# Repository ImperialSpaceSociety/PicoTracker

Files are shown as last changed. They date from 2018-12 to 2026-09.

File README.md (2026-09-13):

# PicoTracker







PicoTracker is a lightweight, low-cost high-altitude balloon tracking platform built around an STM8 microcontroller, HC-12 radio hardware, u-blox GPS, and 433 MHz RTTY telemetry. The project was originally developed by the Imperial College Space Society and returned to active maintenance in 2026.

### Project status

[`v1.4.0`](https://github.com/ImperialSpaceSociety/PicoTracker/releases/tag/v1.4.0) is the current maintained release. It is a source-only release focused on firmware correctness, bounded failure handling, regression testing, STM8 size verification, and clearer project documentation. The original hardware dates from 2018-2019, so current builders should still revalidate component availability, RF configuration, power behaviour, and environmental assumptions.

### Maintainer

This repository is maintained and administered by [Sylvester Kaczmarek](https://SylvesterKaczmarek.com). Maintenance questions, technical changes, release coordination, and collaboration proposals can be raised through GitHub issues or directed to the maintainer through the website.

<p align="center">
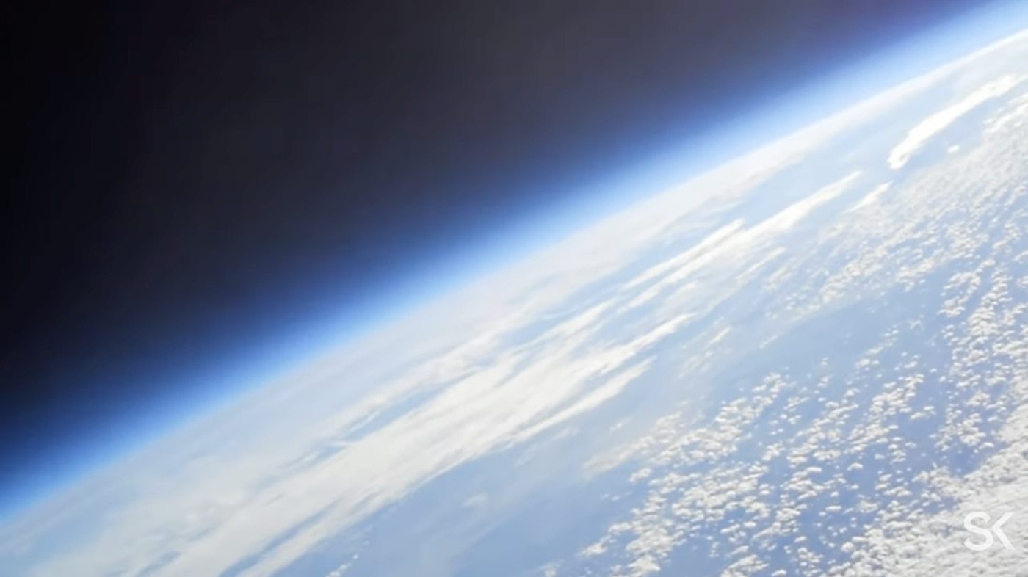
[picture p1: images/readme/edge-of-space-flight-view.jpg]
High-altitude view from a PicoTracker balloon flight
  
</p>
<p align="center"><sub>High-altitude view from one of the project balloon flights.</sub></p>

## Start here

New to PicoTracker? You can get a meaningful first result without any hardware:

```sh
git clone https://github.com/ImperialSpaceSociety/PicoTracker.git
cd PicoTracker
make demo
make test
```

`make demo` decodes the included real telemetry capture, which currently contains **165 valid frames**; `make test` runs the complete host regression suite. The root `Makefile` is the canonical developer entry point:

| Command | Purpose |
| --- | --- |
| `make` / `make help` | Show the available developer commands |
| `make demo` | Decode the included flight capture; no C compiler or hardware required |
| `make simulate` | Run a synthetic end-to-end tracker flight cycle with optional fault injection |
| `make test` | Run all host regression tests |
| `make decode` | Decode a telemetry capture; override with `CAPTURE=path/to/file` |
| `make stm8` | Run the structural STM8 compile/link check; requires SDCC |
| `make quality` | Run C static analysis, Python lint/format checks, and whitespace validation |
| `make format` | Apply Ruff fixes and Python formatting |
| `make release-check` | Validate `VERSION` and `CHANGELOG.md` for `RELEASE_TAG` |
| `make release-notes` | Preview generated notes for `RELEASE_TAG` |
| `make check` | Run quality checks, tests, decoding, simulator, and STM8 verification |
| `make clean` | Remove generated host-test output |
| `make container-build` | Build the reproducible Linux development image |
| `make container-check` | Run the full verification suite inside that image |

For a reproducible Linux toolchain with Python, GCC, Make, SDCC, cppcheck, and Ruff already installed, use the [Dev Container / Docker environment](docs/development-environment.md).

From there, [`docs/getting-started.md`](docs/getting-started.md) gives separate paths into firmware, GPS/UBX, radio/telemetry, Python tooling, testing, hardware, CAD, and documentation. If you want one guided end-to-end exercise first, follow the [`first-project tutorial`](docs/first-project.md). See [`docs/roadmap.md`](docs/roadmap.md) for extension ideas ranging from small first contributions to larger hardware and tooling projects.

## Why work on PicoTracker

PicoTracker is unusual in that one small repository spans almost the complete path from a battery-powered embedded device to received, decoded flight telemetry. You can work on constrained C firmware, GPS protocols, RF control, power management, telemetry, Python tooling, tests, hardware, or CAD and still see how your change fits into the whole system.

The STM8 target has only **8 KB of flash and 1 KB of RAM**, so engineering trade-offs are visible rather than hidden behind abundant resources. At the same time, the repository contains historical flight hardware, launch footage, and real captured telemetry, while the maintained codebase now has regression tests and reproducible structural checks. That combination makes it useful both as a learning platform and as a base for serious improvements in tooling, hardware accessibility, power, validation, and ground-side analysis.

## At a glance

| Item | Current project configuration |
| --- | --- |
| MCU | STM8S003F3, 8 KB flash, 1 KB RAM |
| Radio | HC-12 hardware using Si4463 or compatible Si4438 paths |
| Default RF frequency | 434.570 MHz |
| Telemetry | 50 baud RTTY with XMODEM CRC |
| GPS | u-blox M8 family |
| Radio oscillator | 32 MHz TCXO by default; 30 MHz crystal compatibility retained |
| Processor clock | 16 MHz internal HSI |
| Power | AAA lithium primary cell with 3.3 V boost stage in the original design |
| Current release | [`v1.4.0`](https://github.com/ImperialSpaceSociety/PicoTracker/releases/tag/v1.4.0) |
| Production project | [`firmware/HC12Tracker.ewp`](firmware/HC12Tracker.ewp) |

## System architecture

```mermaid
flowchart LR
    BAT["AAA lithium cell"] --> BOOST["3.3 V boost converter"]
    BOOST --> MCU["STM8S003F3<br/>8 KB flash / 1 KB RAM"]
    BOOST --> GPS["u-blox M8 GPS"]
    BOOST --> RADIO["HC-12 radio<br/>Si4463 / Si4438"]
    MCU <-->|UART| GPS
    MCU <-->|SPI| RADIO
    TCXO["32 MHz TCXO<br/>30 MHz crystal compatible"] --> RADIO
    RADIO --> ANT["433 MHz antenna"]
    ANT -. "434.570 MHz / 50 baud RTTY" .-> GROUND["Ground receiver / HAB decoder"]
```

The STM8 runs from its 16 MHz internal HSI clock. The separate 32 MHz TCXO shown above is the maintained default oscillator for the Si4463 radio; the original 30 MHz crystal path is retained as a compatibility configuration.

## What changed in v1.4.0

`v1.4.0` is the first maintained release following the 2026 firmware and repository hardening work. Major changes include:

- strict UBX payload length, checksum, ACK/NAK, and valid-3D-fix handling
- bounded GPS, UART, STM8 clock-switch, and Si4463 command waits
- corrected Si4463 reset and `POWER_UP` sequencing with explicit error propagation
- corrected telemetry frame sizing, numeric formatting, temperature handling, and operational-status reporting
- preserved last-known valid GPS data when acquisition enters degraded mode
- restored and tested altitude-dependent sleep/wake behaviour and HSI clock recovery
- removed floating-point radio synthesizer arithmetic and reduced firmware footprint for the 8 KB STM8 target
- added host regression tests, telemetry decoder tests, repository metadata checks, and a repeatable STM8 structural compile/link check

See [`CHANGELOG.md`](CHANGELOG.md) for the detailed release history.

## How the tracker operates

A normal cycle acquires and validates a u-blox NAV-PVT solution, reads radio voltage and temperature, constructs a CRC-protected telemetry sentence, transmits it over 433 MHz RTTY, powers down the radio and GPS as appropriate, and enters STM8 auto-wakeup sleep. GPS acquisition and radio command paths are bounded so loss of GPS or a radio CTS failure does not create an intentional infinite wait. If a new valid GPS solution cannot be obtained, the tracker continues in degraded mode while retaining the most recently accepted fix.

At altitudes up to 3000 m the maintained firmware uses one auto-wakeup sleep interval. Above 3000 m it uses two intervals before returning to the HSI clock and beginning the next acquisition/transmit cycle.

You can exercise this state machine without hardware using `make simulate`. The [hardware-independent simulator](docs/simulator.md) supports GPS-loss, measurement-failure, and radio-transmit fault injection and can generate decoder-compatible synthetic telemetry captures.

```mermaid
flowchart TD
    WAKE["Wake from auto-wakeup sleep"] --> HSI["Restore HSI clock"]
    HSI --> GPS["Wake / configure GPS"]
    GPS --> FIX["Acquire NAV-PVT solution"]
    FIX --> VALID{"Valid 3D fix + gnssFixOK?"}
    VALID -- Yes --> MEASURE["Measure radio voltage and temperature"]
    VALID -- "No, retry budget exhausted" --> DEGRADED["Degraded mode<br/>retain last valid fix + update status"]
    DEGRADED --> MEASURE
    MEASURE --> FRAME["Build telemetry sentence + CRC"]
    FRAME --> TX["Transmit 434.570 MHz RTTY"]
    TX --> POWER["Power down radio / GPS as appropriate"]
    POWER --> ALT{"Altitude > 3000 m?"}
    ALT -- Yes --> SLEEP2["Sleep 2 AWU intervals"]
    ALT -- No --> SLEEP1["Sleep 1 AWU interval"]
    SLEEP2 --> WAKE
    SLEEP1 --> WAKE
```

## Configuration

The main flight configuration is intentionally concentrated in a small number of files:

| Setting | Default | Location |
| --- | --- | --- |
| Payload name | `ICSPACE14` | [`firmware/main.h`](firmware/main.h) |
| RF frequency | `434570000` Hz | [`firmware/main.h`](firmware/main.h) |
| RTTY timing | 50 baud configuration | [`firmware/main.h`](firmware/main.h) |
| Radio oscillator | 32 MHz TCXO | [`firmware/HC12Board.h`](firmware/HC12Board.h) |
| 30 MHz crystal compatibility | Supported by removing `XO_TCXO` | [`firmware/HC12Board.h`](firmware/HC12Board.h) |
| Sleep cadence | 1 interval through 3000 m, 2 above | [`firmware/sleep_policy.h`](firmware/sleep_policy.h) |

Review these settings before programming hardware for a new payload or flight. RF frequency, output power, antenna configuration, and balloon operation must also comply with the applicable local requirements.

## Verification and testing

GitHub Actions runs the full reproducible `make check` gate on pushes to `master` and on pull requests. It includes cppcheck for maintained C, Ruff lint/format verification, maintained-tree whitespace validation, the host regression suite, telemetry decoding, the simulator smoke run, repository metadata checks, and the STM8 structural target check.

For `v1.4.0`, the CI SDCC 4.2 structural build used **7,787 / 8,192 bytes** of flash span and **130 / 1,024 bytes** of static DATA. The structural SDCC build uses compatibility shims for IAR-specific registers and interrupt declarations, so it is a target-compiler and memory-window check, not a flashable firmware artifact. The release was approved by the maintainer following target/hardware validation; detailed native-IAR logs and quantitative hardware measurements were not archived with that release.

The root `Makefile` keeps verification commands consistent across local development and CI. Run the fast static gate with `make quality`, the host suite with `make test`, the independent target-structure check with `make stm8`, and the telemetry smoke test with `make decode`. With the development tools installed, the complete repository verification is one command:

```sh
make check
```

The maintained production project for native STM8 development is [`firmware/HC12Tracker.ewp`](firmware/HC12Tracker.ewp). See [`docs/code-quality.md`](docs/code-quality.md) for the quality gate and [`docs/development.md`](docs/development.md) for programming and debugging notes.

Future releases use the tag-driven [`Release` workflow](docs/release-automation.md): an annotated `vX.Y.Z` tag must match `VERSION` and `CHANGELOG.md`, the full reproducible checks must pass, and only then is the GitHub Release created.

## Telemetry

PicoTracker transmits a comma-separated RTTY sentence containing the payload name, sentence ID, UTC time, signed latitude and longitude, altitude, satellite count, radio supply voltage, packed operational status, radio temperature, and a four-digit XMODEM CRC.

```text
PAYLOAD,ID,HHMMSS,+LAT,-LON,ALT,SATS,VOLTAGE,STATUS,+TEMP*CRC
```

The exact field order is documented in [`docs/telemetry-format.md`](docs/telemetry-format.md). The packed status field, including GPS acquisition and measurement failure information, is documented in [`docs/status-word.md`](docs/status-word.md).

## Repository layout

| Path | Purpose |
| --- | --- |
| [`firmware/`](firmware/) | Maintained STM8 tracker firmware and IAR project |
| [`tests/`](tests/) | Host regression tests and STM8 structural target check |
| [`tools/`](tools/) | Telemetry decoder and sample captured data |
| [`hardware/`](hardware/) | Historical hardware design and reference files |
| [`cad/`](cad/) | Mechanical and printable tracker parts |
| [`docs/`](docs/) | Development, GPS, radio, telemetry, release, and validation documentation |
| [`test_firmware/`](test_firmware/) | Historical diagnostic firmware, retained for reference and not release-qualified |

## Documentation

- [`docs/development.md`](docs/development.md) - development, programming, debugging, oscillator configuration, and runtime notes
- [`docs/code-quality.md`](docs/code-quality.md) - static analysis, Python lint/format, and whitespace quality gates
- [`docs/gps.md`](docs/gps.md) - GPS hardware and integration notes
- [`docs/hc12.md`](docs/hc12.md) - HC-12, Si4463/Si4438, oscillator, and processor notes
- [`docs/telemetry-format.md`](docs/telemetry-format.md) - telemetry field order
- [`docs/status-word.md`](docs/status-word.md) - operational-status bit layout
- [`tests/README.md`](tests/README.md) - regression and structural target-test scope
- [`docs/release-checklist.md`](docs/release-checklist.md) - release process
- [`docs/hardware-validation.md`](docs/hardware-validation.md) - target/hardware validation record
- [`CHANGELOG.md`](CHANGELOG.md) - release history

## Project hardware

The repository retains photographs of the original project hardware. These are useful references for identifying the major modules, although current builders should verify the exact revision and components they source.

<table>
  <tr>
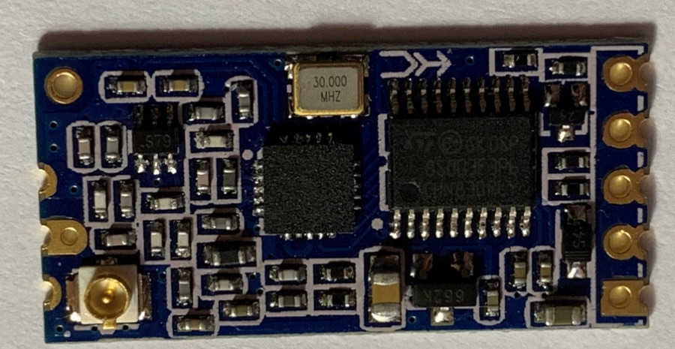
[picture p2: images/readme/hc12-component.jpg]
HC-12 component side
    <td align="center"><br><sub>HC-12 radio / STM8 module</sub></td>
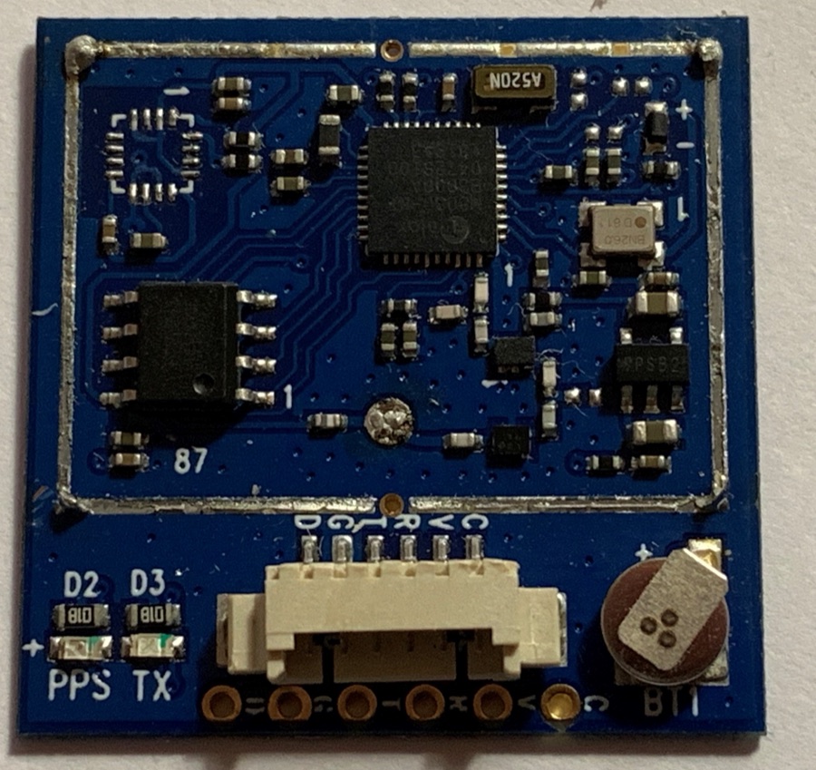
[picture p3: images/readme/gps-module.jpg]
u-blox GPS module
    <td align="center"><br><sub>u-blox GPS module</sub></td>
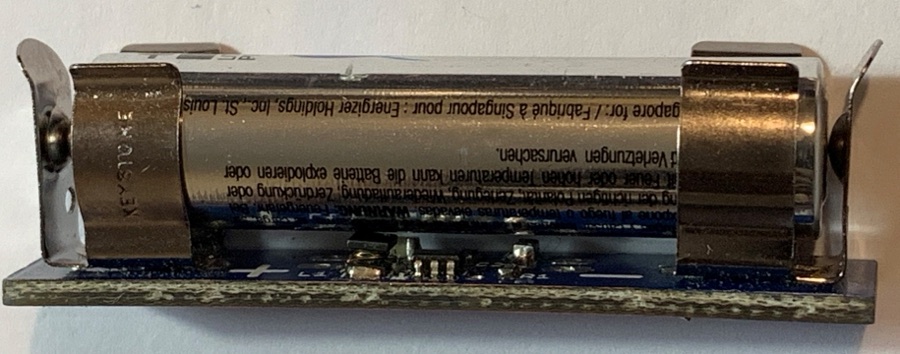
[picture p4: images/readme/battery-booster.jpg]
Battery boost converter
    <td align="center"><br><sub>AAA battery boost converter</sub></td>
  </tr>
</table>

## Flight footage

The project has a larger video archive documenting high-altitude balloon flights from launch through ascent, the edge-of-space phase, and descent. The selected clips below are from [Sylvester Kaczmarek's YouTube channel](https://www.youtube.com/@SylvesterKaczmarek) and give a quick visual sense of the environment PicoTracker was built to operate in.

<table>
  <tr>
    <td width="33%" align="center">
      <a href="https://www.youtube.com/watch?v=IWZ5Tttl32g">High Altitude Balloon 2018: 08 Raising</a><br>
      <strong>Ascent</strong><br>
      <sub><a href="https://www.youtube.com/watch?v=IWZ5Tttl32g">High Altitude Balloon 2018: 08 Raising</a></sub>
    </td>
    <td width="33%" align="center">
      <a href="https://www.youtube.com/watch?v=OtdXHd_AjtY">High Altitude Balloon 2018: 20 The Edge of Space</a><br>
      <strong>Edge of space</strong><br>
      <sub><a href="https://www.youtube.com/watch?v=OtdXHd_AjtY">High Altitude Balloon 2018: 20 The Edge of Space</a></sub>
    </td>
    <td width="33%" align="center">
      <a href="https://www.youtube.com/watch?v=-n3UuoJTzKg">High Altitude Balloon 2018: 34 Landing</a><br>
      <strong>Descent and landing</strong><br>
      <sub><a href="https://www.youtube.com/watch?v=-n3UuoJTzKg">High Altitude Balloon 2018: 34 Landing</a></sub>
    </td>
  </tr>
</table>

More flight footage: [Raising 03](https://www.youtube.com/watch?v=nnN85UmlgXM) · [Edge of Space 11](https://www.youtube.com/watch?v=IkWxLzXfyp0) · [Edge of Space 19](https://www.youtube.com/watch?v=CTOZ2g5Ok2o) · **[watch the full High Altitude Balloon 2018 playlist](https://www.youtube.com/playlist?list=PLf9MwNhV-GcEE7K-Lzd70tIrfB1l1Xk7f)**.

## Hardware design

### GPS

The original design uses a u-blox M8-based GPS module suitable for high-altitude balloon operation. Historical modules incorporated the receiver, TCXO, backup supply, external flash, LNA, SAW filtering, and a ceramic antenna. The original lightweight build concept removed the metal shield and ceramic antenna and replaced the antenna with a wire element and ground plane. Historical mass varied significantly with module and antenna configuration.

### 433 MHz radio and processor

The tracker reprograms the STM8S003F3 processor already present on HC-12 radio hardware and drives the Si4463 directly. The maintained firmware also retains the historical Si4438-compatible detection path. The STM8S003F3 has 8 KB of flash and 1 KB of RAM, making code size and bounded resource use important design constraints.

### Battery

The original battery supply is based on the earlier [BatteryAAA](https://github.com/ribbotson/rlabTelemetryTx/tree/master/Hardware/BatteryAAA) design, using a AAA lithium primary cell and a boost converter to supply approximately 3.3 V to the GPS, radio, and processor. Historical measurements were approximately 8 g for the cell and 3.5 g for the holder and boost converter.

### Tracker body

The tracker body can be 3D printed or made from lightweight foam. The original antenna arrangement placed the GPS antenna at the top and the 433 MHz radio antenna at the bottom. Mechanical files are retained in [`cad/`](cad/).

## Design constraints

PicoTracker is intentionally small and resource-constrained. The main engineering constraints are the 8 KB STM8 flash limit, low-temperature operation, oscillator stability, RF configuration, GPS availability at altitude, and energy consumption during acquisition/transmit/sleep cycles. The original modules and mechanical design were developed in 2018-2019, so a new physical build should be treated as a revalidation of the historical hardware rather than an assumption that every original component or measured property is unchanged.

## Release history

| Release | Date | Status |
| --- | --- | --- |
| [`v1.4.0`](https://github.com/ImperialSpaceSociety/PicoTracker/releases/tag/v1.4.0) | 2026-09-13 | Current maintained release |
| [`v1.3`](https://github.com/ImperialSpaceSociety/PicoTracker/releases/tag/v1.3) | 2019-03-07 | Historical, superseded by v1.4.0 |

## Contributing

Focused firmware fixes, regression tests, decoder/tooling improvements, documentation, hardware validation notes, and well-scoped technical contributions are welcome. New contributors should begin with [`docs/getting-started.md`](docs/getting-started.md), then see [`CONTRIBUTING.md`](CONTRIBUTING.md) before opening a pull request. Project conduct, support, and security reporting are covered by [`CODE_OF_CONDUCT.md`](CODE_OF_CONDUCT.md), [`SUPPORT.md`](SUPPORT.md), and [`SECURITY.md`](SECURITY.md).

## License

PicoTracker uses separate licenses for software and hardware design material:

- Software and firmware: [MIT License](LICENSES/MIT.txt).
- Hardware design documentation: [CERN Open Hardware Licence v1.2](LICENSES/CERN-OHL-1.2.txt), or a later version where the existing project notice permits it.

See [`LICENSE.md`](LICENSE.md) for the repository license split and applicable notices.

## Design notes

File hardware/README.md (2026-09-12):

# Hardware

This directory contains hardware reference material for the PicoTracker project.

- `battery-boost-aaa.pdf` — battery boost reference document.
- `battery-boost-aaa.xlsx` — associated battery boost design data.
- `HC12/` — HC12-related hardware material.

For the overall tracker design and current maintenance status, see the repository root `README.md`.

Hardware design documentation is licensed under the [CERN Open Hardware Licence v1.2](../LICENSES/CERN-OHL-1.2.txt), or a later version where the existing project notice permits it.

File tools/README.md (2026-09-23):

# Tools

Development and analysis helpers for PicoTracker telemetry data are kept here.

## Telemetry decoder

`decode_data.py` scans raw DL-fldigi captures, validates the four-digit telemetry CRC, and reports valid frames and cycle timing. Basic decoding uses only the Python standard library.

Run it against the included sample capture:

```sh
python3 tools/decode_data.py
```

Pass one or more capture files explicitly, or add `--print-frames` to print each accepted frame:

```sh
python3 tools/decode_data.py capture.txt --print-frames
```

Use `--decode-status` to decode the packed operational status (`op_status`) field into
human-readable diagnostics (fix attempts, configuration status, polling status, degraded
mode, and radio measurement failure):

```sh
python3 tools/decode_data.py capture.txt --decode-status
```

Combine `--decode-status` with `--print-frames` to display each frame alongside its
decoded operational status:

```sh
python3 tools/decode_data.py capture.txt --print-frames --decode-status
```

Use `--csv-output` to write all CRC-valid frames from the supplied captures to a
CSV file with headings matching the documented telemetry fields:

```sh
python3 tools/decode_data.py capture.txt --csv-output flight-data.csv
```

Invalid frames are omitted. When multiple captures are supplied, their accepted
frames are written to the same CSV file in command-line order.

Use `--json-output` for a JSON array with the same field names as the CSV headings:

```sh
python3 tools/decode_data.py capture.txt --json-output flight-data.json
python3 tools/decode_data.py first.txt second.txt --json-output flight-data.json --csv-output flight-data.csv
```

Each object represents one accepted frame. All values remain **strings**, preserving
leading zeros, explicit signs, precision, and the original telemetry units. In
particular, `utc_time` stays `HHMMSS`, voltage stays in millivolts, and `op_status`
stays the raw packed decimal value, even when `--decode-status` is also used.

```json
[
  {
    "payload_name": "PICO",
    "sentence_id": "0042",
    "utc_time": "000001",
    "latitude_deg": "+51.536248",
    "longitude_deg": "-000.207353",
    "altitude_m": "1234",
    "satellites": "08",
    "voltage_mv": "3175",
    "op_status": "0004",
    "temperature_c": "-08"
  }
]
```

JSON includes only CRC-valid frames with all ten telemetry fields, in input-file
order and then capture order. No accepted frames produces `[]`. Without input
files, the bundled sample is used as usual. JSON and CSV exports can be requested
together; terminal summaries, `--print-frames`, and plotting remain available.
JSON export uses only the Python standard library.

Plotting is optional. Install the pinned plotting dependency and use `--plot`:

```sh
python3 -m pip install -r tools/requirements.txt
python3 tools/decode_data.py --plot
```

`with_pips_data.txt` is retained as a sample captured dataset and is also exercised by the host regression tests.

## Tracker simulator

`simulate_tracker.py` runs a deterministic hardware-independent flight cycle, including GPS degraded mode, sleep cadence, status packing, telemetry generation, and optional fault injection. From the repository root run:

```sh
make simulate
make simulate SIM_ARGS="--scenario gps-loss --print-frames"
```

See [`docs/simulator.md`](../docs/simulator.md) for scenarios, fault injection, capture generation, and fidelity limits.

## Release metadata helper

`release.py` validates release tags against `VERSION` and `CHANGELOG.md` and renders the notes used by the automated release workflow. From the repository root:

```sh
make release-check RELEASE_TAG=vX.Y.Z
make release-notes RELEASE_TAG=vX.Y.Z
```

See [`docs/release-automation.md`](../docs/release-automation.md) for the publication workflow.

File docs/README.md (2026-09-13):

# Documentation

This directory collects PicoTracker project guides and technical reference material. Some external links are historical and may have moved since the original work.

## Project guides

- [Start here: getting started](getting-started.md)
- [First project: trace a failed telemetry transmission](first-project.md)
- [Project roadmap and extension ideas](roadmap.md)
- [Development and debugging](development.md)
- [Reproducible development environment](development-environment.md)
- [Code quality checks](code-quality.md)
- [Hardware-independent tracker simulator](simulator.md)
- [GPS notes](gps.md)
- [HC12 radio notes](hc12.md)
- [Later tracker design notes](new-tracker.md)
- [Telemetry format](telemetry-format.md)
- [Operational status field](status-word.md)
- [Release checklist](release-checklist.md)
- [Release automation](release-automation.md)
- [Hardware validation matrix](hardware-validation.md)

## Repository indexes

- [Firmware](../firmware/)
- [Test firmware](../test_firmware/)
- [Hardware](../hardware/)
- [CAD](../cad/)
- [Tools](../tools/)

## STM8

- [Datasheet](https://www.st.com/resource/en/datasheet/DM00024550.pdf)
- [Reference Manual](https://www.st.com/resource/en/reference_manual/cd00190271.pdf)
- [Programming Manual](https://www.st.com/resource/en/programming_manual/cd00161709.pdf)
- [Examples](https://github.com/EMBEDONIX/stm8)

## Si4463 and Si446x

- [Datasheet](https://www.silabs.com/documents/public/data-sheets/Si4464-63-61-60.pdf)
- [Programming Guide](https://www.silabs.com/documents/public/application-notes/AN633.pdf)
- [API Documentation](http://www.silabs.com/documents/public/application-notes/EZRadioPRO_REVB1_API.zip)

## HC12

- [Serial Module Manual](https://www.elecrow.com/download/HC-12.pdf)
- [Board information](https://github.com/TG9541/stm8ef/wiki/Board-HC12)

## Bristol SEDS

- [PicoTracker GitHub](https://github.com/bristol-seds/pico-tracker)
- [HC12 Crystal Problem Discussion](https://picaxeforum.co.uk/threads/hc-12-working-supply.29875/page-3)
- [More on HC12 Crystal](https://hackaday.com/2018/05/05/fail-of-the-week-never-assume-all-crystals-are-born-equal/)

## HAB

- [UKHAS Google Group](https://groups.google.com/forum/#!forum/ukhas%5B261-280%5D)

## uBlox

- [BN-220](https://surehobby.com/desc/HR/HR5512/BN_220_GPS_Antenna_datasheet.pdf)
- [UBX-M8030 Specification](https://content.u-blox.com/sites/default/files/products/documents/UBX-M8030_ProductSummary_%28UBX-15029937%29.pdf)
- [Protocol Specification](https://content.u-blox.com/sites/default/files/products/documents/u-blox8-M8_ReceiverDescrProtSpec_UBX-13003221.pdf)

## IAR Embedded Workbench for STM8

- [Download](https://www.iar.com/iar-embedded-workbench/#!?architecture=STM8)
- [User Guides](https://wwwfiles.iar.com/stm8/guides/EWSTM8_DevelopmentGuide.pdf)

## ST-Link programmer/debugger

- [ST-LINK/V2](https://www.st.com/en/development-tools/st-link-v2.html)

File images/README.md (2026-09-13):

# Project images

This directory contains historical hardware photographs and development screenshots used by the PicoTracker documentation.

Image filenames use lowercase kebab-case with lowercase extensions, for example `hc12-component.jpg`. The `readme/` subdirectory contains smaller, optimized copies used on the repository landing page; the full-resolution source photographs remain in this directory.

When adding a new image, use a descriptive lowercase filename, avoid spaces and underscores, and update any documentation links in the same change.

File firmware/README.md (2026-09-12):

# Firmware

This directory contains the STM8 firmware for the PicoTracker HC12-based tracker.

## Main files

- `main.c` / `main.h` - application startup, GPS acquisition, measurements, and tracker control flow.
- `gps.c` / `gps.h` - u-blox GPS configuration, polling, and fix handling.
- `telemetry.c` / `telemetry.h` - telemetry generation and transmission control.
  See [`../docs/telemetry-format.md`](../docs/telemetry-format.md) for the transmitted field order.
- `energy.c` / `energy.h` - power and sleep-related functions.
- `si_trx.c` / `si_trx.h` - Si4463 radio interface.
- `spi_bitbang.c` / `spi_bitbang.h` - software SPI interface used by the radio code.
- `rtty.c` / `rtty.h` - RTTY support.
- `HC12Board.h` - HC12 board and STM8 hardware definitions.
- `HC12Tracker.ewp` - IAR Embedded Workbench project file.

Additional headers and helpers provide numeric formatting, UBX parsing, status packing, telemetry CRC/field formatting, radio measurement conversion, and sleep-policy logic.

## Development

See [`../docs/development.md`](../docs/development.md) for build, programming, and debugging notes. Generated IAR workspace, debugger, log, and build-output files are intentionally excluded by the repository `.gitignore`.

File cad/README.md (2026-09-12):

# CAD files

Mechanical design files used by the PicoTracker project are kept here.

- `battery-clip.stl` - battery-retention clip.
- `hc12-clip.stl` - HC12 module clip.
- `tinytrack.stl` - tracker body mesh.
- `tinytrack-v7.f3d` - editable Fusion 360 design source.

These files are historical design assets and should be checked against the intended hardware revision before fabrication.

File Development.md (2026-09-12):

# Code Development, Programming and Debugging the HC12 Radio Module

How to develop code, program, and debug the embedded STM8S003F3 processor on the HC12 radio module.

## Code Development

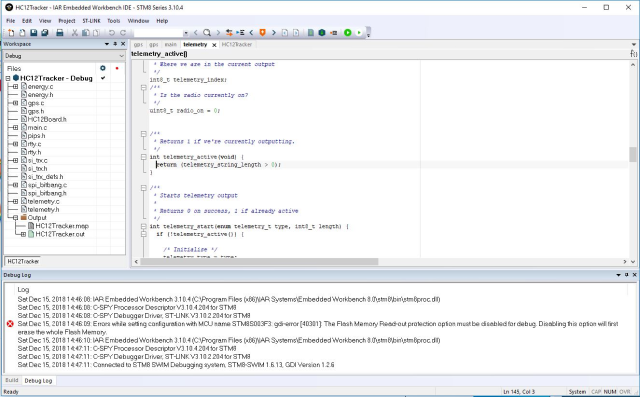
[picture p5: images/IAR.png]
IAR Embedded WorkBench


We use IAR Embedded Workbench for STM8. This is a professional development environment. IAR offers a limited code-size version supporting up to 8K, which matches the STM8S003F3 flash size used by this project.

* The 8K code-size limit is the same as the code size on the STM8S003F3.
* The source of the libraries is not provided, but we do not use them.
* It is available for Microsoft Windows.
* We do not use the code for commercial purposes.

Download the evaluation version and obtain a license for the free 8K code-limited version.

If these limitations are an issue, other compilers are available, such as [SDCC](http://sdcc.sourceforge.net/).

## Programming and Debugging

To program the STM8S003F3 flash, we use the [ST-LINK/V2](https://www.st.com/en/development-tools/st-link-v2.html) or one of the low-cost clones available. The clones we have tested work well.

The ST-LINK/V2 is wired to the HC12 using the GND, RST, SWIM, and 3.3V/VCC connections. The VCC connection powers the HC12 from the clone. The SWIM and RST pads are adjacent to the TXD and RXD pads on the rear of the PCB.

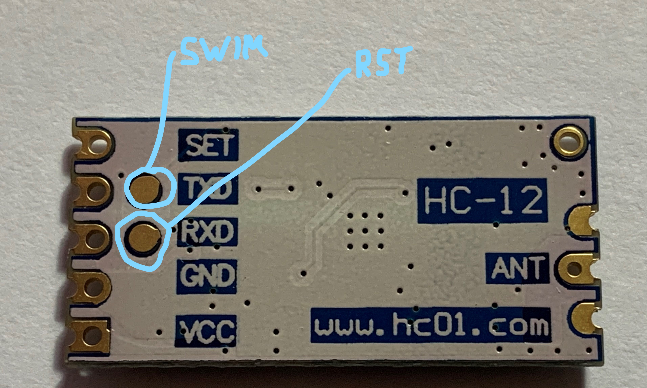
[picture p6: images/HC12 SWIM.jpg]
SWIM Connections

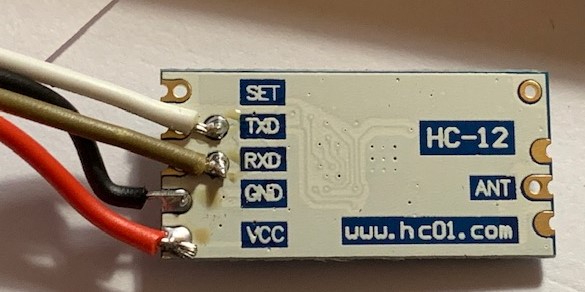
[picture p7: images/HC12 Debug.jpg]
HC12 Debug

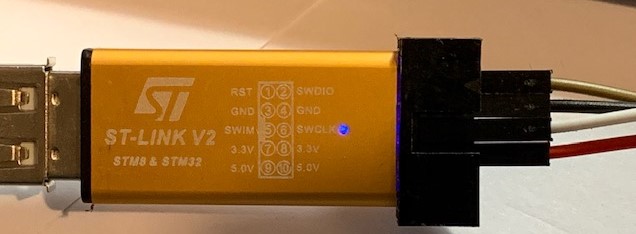
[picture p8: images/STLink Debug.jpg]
ST-Link Debug


The HC12 as purchased comes with custom code that is Read Out Protected (ROP). This must be disabled by erasing the flash of the STM8S003F3. This is done using the Option Bytes selection from the IAR Embedded Workbench ST-LINK menu.

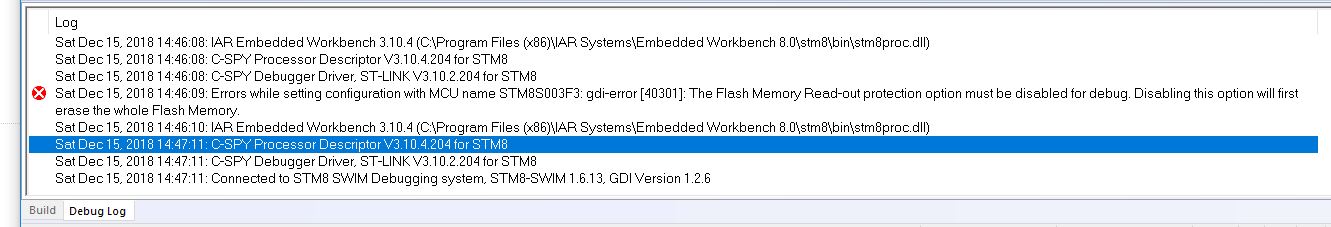
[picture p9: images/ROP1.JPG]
ROP1

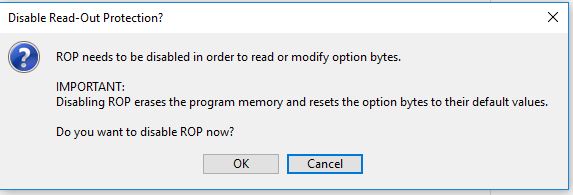
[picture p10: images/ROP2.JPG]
ROP2


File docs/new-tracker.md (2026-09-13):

# Target Requirements for New ICSEDS Pico Tracker

## Environmental
* Temperature Range -40 deg. C to 40 deg. C
* Humidity 0 to 100% RH
* Pressure 0 to 1100mbar

## Cost
* Component cost < 30 UK pounds
## Weight
* Weight with battery 15g max
* Weight with Solar 10g max
## Construction
* Suitable for hand or automated assembly
* 0.8mm thick PCB
## Power
* Battery Lithium Primary Cell 1.5V AAA size. Life > 10 days
* Solar cells
* Efficient  power control of all devices to achieve lowest power standby
## GPS
* UbLox M8
* Onboard antenna
* Good sensitivity
* Output to GPS discipline radio clocks
## Sensors
* Accelerometer and Magnetometer (option)
* Temperature, Pressure and humidity (option)
* Light sensor (option)
* Battery or solar voltage
## Radio
* TCXO stable
* GPS discipline clocks
* 433 MHz RTTY
* 433/868/ 916 MHz LoRa/LoRaWAN
* 144 MHz APRS
* Onboard Antenna

## Processor
* Low power ARM 32 bit processor
* At least 64K Flash memory
* At least 16K RAM memory
*  USB field programming
* Spare I2C
* LED, buttons and display (option). Enable the tracker to be used a LoRaWAN or APRS terrestrial tracker
* Robust power on reset
## Firmware
* Arduino or Similar free IDE C/C++ development environment

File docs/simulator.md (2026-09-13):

# Hardware-independent tracker simulator

`tools/simulate_tracker.py` models the maintained PicoTracker control and telemetry cycle without requiring STM8 hardware, GPS, radio equipment, or IAR.

It is intended for development, teaching, fault-injection experiments, and regression testing. It is **not** an RF propagation, battery-life, atmospheric, or balloon-dynamics simulator.

## What it models

The simulator mirrors the current firmware behaviour that can be represented deterministically on a host machine:

- bounded GPS acquisition with a maximum of 15 attempts
- degraded mode when no valid GPS fix is obtained
- retention of the last valid GPS position, altitude, satellite count, and UTC time during GPS loss
- fresh voltage and temperature measurements on each cycle
- measurement-failure status and zeroed failed measurements
- packed operational-status values
- one AWU sleep interval through 3000 m and two intervals above 3000 m
- the current 30.720 s AWU interval
- current telemetry formatting and XMODEM CRC
- radio-transmit failures as dropped telemetry frames

## Quick start

From the repository root:

```sh
make simulate
```

The default synthetic flight climbs from the ground through the 3000 m sleep-policy threshold to 30 km and then descends. Each line reports the ground-truth altitude, the altitude currently held by the tracker, GPS acquisition state, attempt count, packed status, sleep cadence, and radio-transmit result.

Use the built-in GPS-loss scenario to observe degraded operation and recovery:

```sh
make simulate SIM_ARGS="--scenario gps-loss --print-frames"
```

A mixed-fault scenario additionally injects radio-measurement and transmit failures:

```sh
make simulate SIM_ARGS="--scenario faults"
```

The simulator is deterministic, so the same inputs produce the same sequence and telemetry.

## Fault injection

Cycle numbers can be supplied as individual values or ranges:

```sh
make simulate SIM_ARGS="--gps-loss 6-8 --measurement-fail 10 --tx-fail 12,14"
```

Successful GPS acquisition can also be delayed to exercise retry-status reporting:

```sh
make simulate SIM_ARGS="--gps-attempts 4"
```

The simulator follows the current firmware's status semantics, including the fact that a successful fix after previous failed polls may still report a transient or retry-exhausted polling state for that cycle.

## Generate a synthetic capture

Write only successfully transmitted frames to a raw capture file:

```sh
make simulate SIM_ARGS="--scenario faults --capture /tmp/picotracker-sim.txt"
make decode CAPTURE=/tmp/picotracker-sim.txt
```

The generated capture uses the same sync prefix, field layout, and CRC convention expected by `tools/decode_data.py`.

## Fidelity and limitations

The synthetic altitude/position profile is deliberately simple and exists to exercise tracker behaviour, not to predict a real balloon trajectory. Simulated UTC advances by the configured AWU sleep duration; active GPS acquisition, telemetry transmission, oscillator switching, and other execution time are not included in that clock.

Key simulator constants are regression-tested against the maintained firmware headers and `energy.c`, and a known historical telemetry frame is used as a formatting/CRC reference vector. Simulated captures are also passed through the real telemetry decoder in the host test suite.

For target timing, RF behaviour, current consumption, GPS performance, and environmental behaviour, physical hardware validation remains authoritative.

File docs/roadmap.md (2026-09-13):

# Project roadmap and extension ideas

PicoTracker `v1.4.0` is a maintained baseline, not an endpoint. The most useful future work is work that preserves the project's small, understandable character while improving reproducibility, observability, hardware accessibility, or flight confidence.

## Near-term contribution areas

### Open and reproducible tooling

- strengthen the SDCC/open-toolchain path beyond the current structural compile/link check
- improve automated size reporting and regression limits
- make telemetry capture, decoding, and analysis easier to reproduce on a clean machine

### Telemetry and ground tooling

- add structured export formats such as CSV or JSON to the decoder
- provide small visualization or analysis tools for captured flights
- improve diagnostic interpretation of the operational-status field

### Firmware assurance

- add targeted boundary and failure-path tests
- continue reducing assumptions around peripheral faults and recovery
- profile stack/RAM use and long-duration behaviour on target hardware

### Hardware refresh

- document a current, purchasable component set for a new build
- revalidate the power stage, oscillator options, RF path, GPS modules, and antennas
- preserve compatibility with historical hardware where that remains useful

### Power and environmental validation

- measure acquisition, transmit, and sleep currents on real hardware
- document cold-temperature behaviour and oscillator stability
- turn measurements into a simple energy budget for flight planning

### Mechanical design

- review the existing CAD for current modules and manufacturing methods
- reduce mass while retaining antenna separation and practical assembly
- document repeatable assembly and strain-relief choices

## Contribution scale

A useful contribution does not have to be large. Good starter work includes decoder features, documentation, regression tests, measurement scripts, and reproducible hardware notes. Intermediate work can cover protocol handling, low-power behaviour, build tooling, or CAD changes. Larger projects include a current hardware revision, a fully open target toolchain, or richer ground-station tooling.

The project should remain understandable enough that a new contributor can trace a telemetry value from sensor or GPS input through firmware, radio transmission, capture, and decoder output.

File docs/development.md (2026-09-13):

# Development and debugging

How to develop code, program, and debug the embedded STM8S003F3 processor on the HC12 radio module.

## Code development

IAR Embedded WorkBench

We use IAR Embedded Workbench for STM8. This is a professional development environment. IAR offers a limited code-size version supporting up to 8K, which matches the STM8S003F3 flash size used by this project.

* The 8K code-size limit is the same as the code size on the STM8S003F3.
* The source of the libraries is not provided, but we do not use them.
* It is available for Microsoft Windows.
* We do not use the code for commercial purposes.

Download the evaluation version and obtain a license for the free 8K code-limited version.

If these limitations are an issue, other compilers are available, such as [SDCC](http://sdcc.sourceforge.net/).

## Programming and debugging

To program the STM8S003F3 flash, we use the [ST-LINK/V2](https://www.st.com/en/development-tools/st-link-v2.html) or one of the low-cost clones available. The clones we have tested work well.

The ST-LINK/V2 is wired to the HC12 using the GND, RST, SWIM, and 3.3V/VCC connections. The VCC connection powers the HC12 from the clone. The SWIM and RST pads are adjacent to the TXD and RXD pads on the rear of the PCB.

SWIM Connections
HC12 Debug
ST-Link Debug

The HC12 as purchased comes with custom code that is Read Out Protected (ROP). This must be disabled by erasing the flash of the STM8S003F3. This is done using the Option Bytes selection from the IAR Embedded Workbench ST-LINK menu.

ROP1
ROP2
## Runtime configuration notes

Radio oscillator selection is controlled in `firmware/HC12Board.h`. `XO_SOURCE` and `XO_FREQUENCY` are the authoritative Si4463 power-up settings; defining `XO_TCXO` selects the 32 MHz TCXO path, while removing it selects the original 30 MHz crystal path.

The tracker uses one auto-wakeup sleep interval at altitudes up to 3000 m and two intervals above 3000 m. After the final wake-up, the STM8 switches back to the HSI clock before the next GPS and telemetry cycle.

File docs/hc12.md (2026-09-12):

# HC12 Radio and Processor Module

The HC12 is an Si4463-based radio module with an STM8S003F3 processor. The original modules were inexpensive and supplied with serial-interface firmware, but the STM8 can be reprogrammed for tracker use. The STM8S003F3 provides 8 KB of flash and 1 KB of RAM, so firmware size remains a constraint. Historical module mass was approximately 1 g.

## HC12 versions
The HC12 module appears to have been originally produced by HC01; the original company website is no longer available. Subsequently it appears the HC12 has been cloned by a number of other companies with some changes along the way. The primary changes appear to be the use of the 20 pin QFN processor package instead of the 20 pin TSSOP package, and the use of the Si4438 radio instead of the Si4463. The Si4438 is pin and firmware compatible with the Si4463 but has a frequency range limited to the 433MHz band which is not a problem for us.
The clone HC12 modules have come under a lot of criticism for poor performance and devices from different suppliers not interworking. The Processor and Radio ICs appear to be genuine manufacturers parts and the issues seem to be related to the poor quality of the crystal used for the radio IC. [Crystal Fail!](https://hackaday.com/2018/05/05/fail-of-the-week-never-assume-all-crystals-are-born-equal/)

## Si4463 Radio
The Silabs SI4463 Radio IC has been successfully used in a number of existing HAB tracker designs including those from [Bristol SEDS](https://github.com/bristol-seds/pico-tracker) and [PecanPico](https://github.com/DL7AD/pecanpico10). The Si4463 IC is capable of operation over wide frequency range from 119MHz to 1050MHz, but implementations usually limit operation to a single band. In our case we use the 433MHz band but other implementations with different RF configurations and component values can operate in the 144MHz and 868MHz bands. The Si4438 IC is limited to frequencies between 425 and 525 Mhz, and has fewer modulation options.
The Si4463 is a transceiver but at this time we are only using the transmit functions.

## Radio Crystal Issues
As quoted above many users have had problems with the crystals used on the clone HC12 module which result in the module being off frequency. We discovered that the crystal problem also manifested itself in wide frequency drift during transmission. Replacement of the crystal on the HC12 module resolved this issue.

## STM8S003F3 Processor

## Processor Clock

## Temperature Management

## Power Management

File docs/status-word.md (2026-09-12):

# Operational status field

The telemetry `op_status` value is a packed diagnostic field assembled in `firmware/main.c` and stored as a 16-bit value in `struct gps_fix`.

The low byte contains GPS acquisition diagnostics, and bit 8 records a radio measurement failure.

| Bits | Meaning |
| --- | --- |
| 8 | Radio ADC measurement failed during the current cycle |
| 7..4 | GPS fix poll attempts, saturated at 15 |
| 3..2 | GPS configuration status |
| 1..0 | GPS polling status |

For the two status subfields, value `0` means no recorded failure, `1` records a transient failure, and `2` records retry exhaustion. For the GPS polling field, value `3` means fix acquisition reached its overall attempt limit and the tracker continued in degraded mode.

The attempt counter is also the acquisition budget: a fix cycle performs at most 15 NAV-PVT polls. If no valid 3D solution is obtained, telemetry continues with polling status `3` instead of blocking indefinitely.

If bit 8 is set, the affected voltage or temperature field is emitted as `0` rather than presenting stale or command-buffer data as a measurement.

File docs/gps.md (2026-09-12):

# uBlox M8 GPS

We decided to consider GPS modules based on the uBlox M8 because of their functionality, low cost, and support for high-altitude operation.

## M8N Capabilities

These GPS units, based on the UBX-G8030 IC, support multiple GNSS constellations (GPS, GLONASS, QZSS, and SBAS). With external flash, they can also support Galileo and BeiDou.

In airborne mode, the M8 modules are capable of operating up to a maximum altitude of 50 km.

## GPS Modules based on M8

Our early development was based on uBlox MAX-M8 modules, but these required PCB mounting and were expensive in small quantities. The uBlox NEO-M8 adds a low-noise amplifier (LNA) and SAW filter, and clones are available at low cost, but again they require PCB mounting.

We found the following UBX-G8030-based boards with LNA and SAW filters to be low cost and easy to connect without an additional PCB. They all have flash memory and battery backup.

* Beitian BN-280: The module is available with and without a compass. We do not use the compass and do not have an I2C interface available on the HC12, so either is suitable. The interface has six pins, including two unused I2C pins for the compass. The unmodified module weighs 13.5 g; removing the ceramic antenna and screening can gives a weight of 2.5 g.

* Beitian [BN-220](https://surehobby.com/desc/HR/HR5512/BN_220_GPS_Antenna_datasheet.pdf): This is the smaller sibling of the BN-280 at 22 mm × 20 mm × 6.5 mm. It has an integrated antenna and a four-pin interface. The unmodified module weighs 5.6 g.

* TOPGNSS [GG-1802](http://www.stotoncn.com/gnssmodule/showproduct.php?lang=en&id=63)/[GB-1803](http://www.stotoncn.com/gnssmodule/product.php?lang=en&class3=110): These are the smallest GPS modules we used, at 18 mm × 18 mm × 6.2 mm. They have an integrated antenna and a five-pin interface including a 1PPS output. The GG-1802 uses GPS and GLONASS by default, while the GB-1803 uses GPS and BeiDou by default. The unmodified module weighs 7.25 g; removing the ceramic antenna gives a weight of 1.6 g. We estimated that removing the screening can and connector could reduce this to around 1 g.

At the time of the original project, the modules above were available for around £6 each. They worked for our prototypes and appeared to use genuine uBlox chips.

## Firmware fix acceptance

The firmware polls `UBX-NAV-PVT` and accepts a response only after its UBX checksum is valid and its payload length matches the 92-byte NAV-PVT payload.

A navigation solution is accepted for tracking only when `fixType` is `3` (3D fix) and the `gnssFixOK` flag is set. 2D, dead-reckoning-only, combined GNSS/dead-reckoning, time-only, and unvalidated fixes are not accepted as position solutions.

## GPS Power Consumption

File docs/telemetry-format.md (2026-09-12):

# Telemetry format

PicoTracker builds a comma-separated RTTY telemetry sentence from the latest GPS fix and radio measurements. The field order is defined by `prepare_tx_buffer()` in `firmware/telemetry.c`, with field sizes and offsets in `firmware/main.h`.

The transmitted data fields are:

1. payload name or callsign from `PAYLOAD_NAME`
2. incrementing sentence ID
3. UTC time as `HHMMSS`
4. signed latitude in decimal degrees
5. signed longitude in decimal degrees
6. altitude in metres
7. number of satellites used in the solution
8. radio supply voltage in millivolts
9. packed operational-status value
10. signed radio temperature
11. XMODEM CRC checksum

Latitude and longitude are derived from the u-blox integer coordinates scaled by `10^7`. The firmware inserts the decimal point when constructing the telemetry sentence.

The operational-status field is formatted as a four-digit decimal value. See [`status-word.md`](status-word.md) for the packed diagnostic bit layout and status meanings.

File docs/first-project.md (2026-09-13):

# First project: trace a failed telemetry transmission

This tutorial is a hardware-free practice project for a first PicoTracker contribution. It takes one small change through the same loop used for real work: reproduce behaviour, edit code, add a regression test, run the project gates, inspect the diff, and prepare a pull request.

The exercise adds a named `radio-loss` simulator scenario. It is intentionally small and should be treated as practice rather than submitted as a pull request; use the same workflow on an open issue for a real contribution.

## What you will learn

By the end you will have:

- run real captured telemetry through the decoder;
- reproduced a simulated radio-transmit failure;
- changed one Python control path;
- added a regression test for that change;
- generated and decoded a synthetic telemetry capture;
- run the same checks used by CI; and
- inspected the exact diff a maintainer would review.

No STM8 board, GPS receiver, radio, IAR installation, or RF equipment is required.

## 1. Prepare a clean branch

For a real contribution, first fork PicoTracker on GitHub, then clone your fork and add the main repository as `upstream`:

```sh
git clone https://github.com/YOUR-USERNAME/PicoTracker.git
cd PicoTracker
git remote add upstream https://github.com/ImperialSpaceSociety/PicoTracker.git
git switch -c tutorial/radio-loss-scenario
make demo
make test
```

Replace `YOUR-USERNAME` with your GitHub login. If you only want to do the exercise locally, you may instead clone `ImperialSpaceSociety/PicoTracker` directly and skip the `upstream` remote.

`make demo` should report **165 valid frames**. `make test` should complete without failures before you change anything; that gives you a known-good baseline.

If you use the repository Dev Container, the complete compiler, SDCC, cppcheck, and Ruff toolchain is already available. See [`development-environment.md`](development-environment.md).

## 2. Reproduce the behaviour first

The simulator already lets you inject a one-off transmit failure. Run 14 cycles, fail transmission on cycle 12, and write the successfully transmitted frames to a temporary capture:

```sh
make simulate SIM_ARGS="--cycles 14 --tx-fail 12 --capture /tmp/picotracker-tutorial.txt"
```

Near the end of the output you should see cycle 12 marked `FAILED`, followed by:

```text
Summary: cycles=14 degraded=0 measurement_failures=0 tx_failures=1 double_sleep=10 sleep_time=737.280s
Wrote 13 transmitted frames to /tmp/picotracker-tutorial.txt
```

Now decode that generated capture with the normal decoder:

```sh
make decode CAPTURE=/tmp/picotracker-tutorial.txt
```

Expected result:

```text
/tmp/picotracker-tutorial.txt: 13 valid frames
```

This is the important end-to-end observation: the simulator completed 14 tracker cycles, but only 13 frames reached the synthetic ground capture because cycle 12 failed to transmit.

## 3. Add a named scenario

Open [`tools/simulate_tracker.py`](../tools/simulate_tracker.py). In `scenario_faults()`, add a named scenario that produces the same transmit failure:

```python
if name == "radio-loss":
    return set(), set(), {12}
```

Then add `"radio-loss"` to the `--scenario` choices in `main()`.

The three sets returned by `scenario_faults()` are, in order, GPS-loss cycles, measurement-failure cycles, and transmit-failure cycles. This scenario therefore changes only transmission behaviour.

Do not change the telemetry format or embedded firmware for this exercise.

## 4. Add the regression test

Open [`tests/test_simulate_tracker.py`](../tests/test_simulate_tracker.py) and add a focused test inside `TrackerSimulatorTests`:

```python
def test_named_radio_loss_scenario(self):
    gps_loss, measurement_fail, tx_fail = sim.scenario_faults("radio-loss")
    self.assertEqual(gps_loss, set())
    self.assertEqual(measurement_fail, set())
    self.assertEqual(tx_fail, {12})

    results = sim.run_simulation(
        sim.synthetic_profile()[:14],
        tx_fail_cycles=tx_fail,
    )
    self.assertFalse(results[11].tx_success)
```

`results[11]` is cycle 12 because Python lists are zero-indexed. The test checks both pieces of the contract: the named scenario selects only cycle 12 for transmit failure, and the simulator actually reports that cycle as not transmitted.

Avoid testing unrelated behaviour in the same test. Small tests are easier to diagnose and easier for a maintainer to review.

## 5. Format and test the change

Run:

```sh
make format
make test
```

Then exercise the new named path:

```sh
make simulate SIM_ARGS="--scenario radio-loss --cycles 14 --capture /tmp/picotracker-tutorial.txt"
make decode CAPTURE=/tmp/picotracker-tutorial.txt
```

You should again see one transmit failure and **13 valid frames** in the capture.

For the complete repository gate, run either:

```sh
make check
```

or, with Docker:

```sh
make container-check
```

`make check` includes static analysis, Python quality checks, host regression tests, decoder and simulator smoke tests, and the SDCC structural STM8 build. The structural SDCC image is a compile/link and memory-window check; it is not flashable firmware.

## 6. Review your own diff

Before asking someone else to review a change, inspect exactly what changed:

```sh
git status --short
git diff -- tools/simulate_tracker.py tests/test_simulate_tracker.py
```

The output of `git diff` is essentially the same change view GitHub shows in a pull request under **Files changed**. Green lines are additions and red lines are removals.

For this exercise, the intended diff is only the simulator scenario and its regression test. Generated captures under `/tmp` should not appear in Git at all.

## 7. Understand the system connection

The practice change is in the hardware-independent simulator, but it models a real tracker boundary:

1. the tracker acquires or retains a navigation fix;
2. it builds a CRC-protected telemetry frame;
3. the radio transmission either succeeds or fails;
4. only successfully transmitted frames can appear in a ground capture; and
5. the decoder validates the frames that were actually received.

That is why the exercise uses both the simulator and the decoder rather than stopping at a unit test. You are checking behaviour across two project layers.

For the embedded implementation, follow [`firmware/main.c`](../firmware/main.c) into [`firmware/telemetry.c`](../firmware/telemetry.c) and [`firmware/si_trx.c`](../firmware/si_trx.c). Do not change those files merely to complete this tutorial.

## 8. Apply the workflow to a real contribution

Do **not** open a pull request containing the exact `radio-loss` tutorial change. Restore the practice edits when you are finished:

```sh
git restore tools/simulate_tracker.py tests/test_simulate_tracker.py
```

Then choose an open issue or another agreed task and use the same loop:

**reproduce → make one focused change → add evidence/tests → run checks → inspect the diff → open a pull request**.

For a real task, create a fresh branch from current `master`, commit only the relevant files, and push that branch to your fork:

```sh
git switch master
git pull --ff-only upstream master
git switch -c feature/short-description
git add path/to/changed-file path/to/test-file
git commit -m "type: concise description"
git push -u origin feature/short-description
```

Open the pull request against `ImperialSpaceSociety/PicoTracker:master`. In the PR description, state what changed, why it changed, and exactly how you validated it. The repository will request the code owner's review automatically and the required CI check must pass before merge.

If a maintainer requests changes, update the same branch and push again; the existing pull request updates automatically. Do not open a replacement PR for every revision.

## Next steps

After this tutorial, choose a path in [`getting-started.md`](getting-started.md), inspect the open issues, or use [`roadmap.md`](roadmap.md) to understand larger project directions. For contribution rules and review expectations, see [`../CONTRIBUTING.md`](../CONTRIBUTING.md).

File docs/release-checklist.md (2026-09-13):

# Release checklist

Use this checklist before creating a PicoTracker release tag. The current version is recorded in [`../VERSION`](../VERSION).

**v1.4.0 record:** repository/CI gates passed and the maintainer reported successful target/hardware validation. Native IAR build metadata and a flashable binary artifact were not archived, so this release is source-only.

## Source and regression gates

- [ ] `master` is clean and contains the intended release changes.
- [ ] `VERSION` is changed from the development suffix to the release version.
- [ ] `CHANGELOG.md` contains release notes for that exact version.
- [ ] `make release-check RELEASE_TAG=vX.Y.Z` passes.
- [ ] `make release-notes RELEASE_TAG=vX.Y.Z` has been reviewed.
- [ ] GitHub Actions host tests pass on the release commit.
- [ ] `make check` passes locally with an STM8-capable SDCC installation.
- [ ] All IAR project source references resolve to tracked files.
- [ ] No release-blocking TODO, known infinite wait, or unresolved protocol error remains.

## Target build gates

Only the maintained `firmware/HC12Tracker.ewp` project is a release target. The projects under `test_firmware/` are historical diagnostics and are not release-qualified.

- [ ] All production IAR project source references resolve to tracked files.
- [ ] Independent SDCC STM8 structural compile/link passes within the STM8S003F3 flash/RAM window.
- [ ] Native IAR target build and operation have been validated for this release where the toolchain/hardware is available.
- [ ] Native IAR version/build-size output and any flashable binary intended for publication are archived.
- [ ] If a native binary is unavailable, the maintainer has explicitly approved a source-only release and recorded that limitation.

## Hardware gates

- [ ] GPS acquisition, telemetry, radio transmission, sleep/wake, and power cycling have been accepted on the intended hardware, where applicable.
- [ ] [`hardware-validation.md`](hardware-validation.md) records the validation basis, hardware configuration, and any missing measurements or limitations.
- [ ] Any source-only or hardware-not-revalidated exception is explicitly approved by the maintainer before tagging.

## Release publication

- [ ] Review [`../LICENSE.md`](../LICENSE.md) and the standalone license files.
- [ ] Update README verification status if target validation is complete.
- [ ] Create and push an annotated `vX.Y.Z` tag only after all required gates pass.
- [ ] Confirm the automated `Release` workflow completes successfully.
- [ ] Confirm the generated GitHub Release contains the intended changelog section and release commit.
- [ ] If a native-IAR/hardware-validated firmware artifact is available, attach it separately with its checksum.
- [ ] If no validated firmware artifact is available, retain the release as source-only and do not attach the SDCC structural image.

See [`release-automation.md`](release-automation.md) for the tag-driven publication process.

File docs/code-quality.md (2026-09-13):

# Code quality checks

PicoTracker keeps the quality gate intentionally small and deterministic. The canonical command is:

```sh
make quality
```

It runs three checks:

- `cppcheck` on the maintained `firmware/` C sources with warning, performance, and portability diagnostics enabled
- Ruff linting and formatting verification for Python under `tools/` and `tests/`
- trailing-whitespace and final-newline validation for maintained text files

Host C regression tests are also compiled with `-Wall -Wextra -Werror`, so compiler warnings in host-testable firmware logic are already treated as failures.

## Python formatting

Ruff is pinned by the reproducible development container and configured in [`../pyproject.toml`](../pyproject.toml). To apply its safe lint fixes and formatter locally:

```sh
make format
```

`make quality` never modifies files; it only verifies them.

## Historical material

The whitespace gate deliberately excludes `hardware/`, `test_firmware/`, `cad/`, and the raw telemetry capture. Those paths contain preserved historical or binary/raw artifacts where mass cosmetic rewrites would obscure provenance without improving maintained code quality.

The production `firmware/` sources are included. Their pre-existing trailing whitespace was normalized when this gate was introduced; no functional C formatting rewrite was performed.

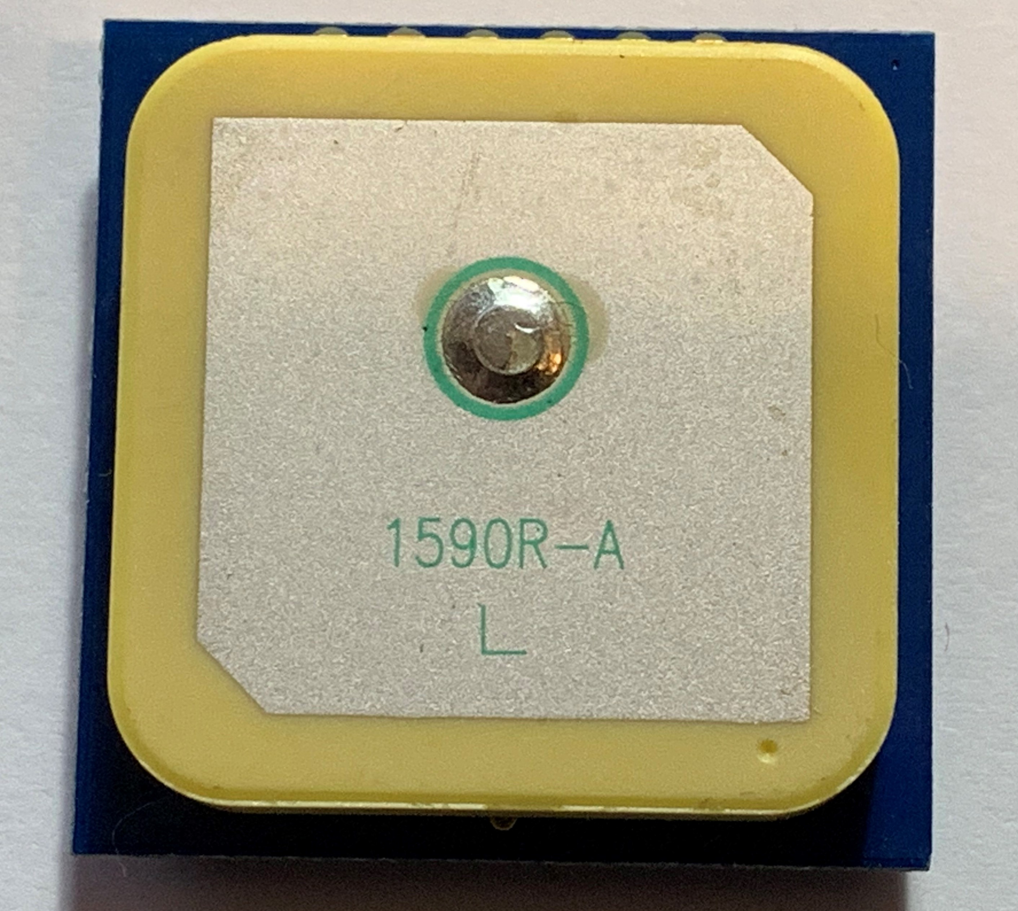
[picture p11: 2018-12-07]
images/gps-ceramic-antenna.jpg

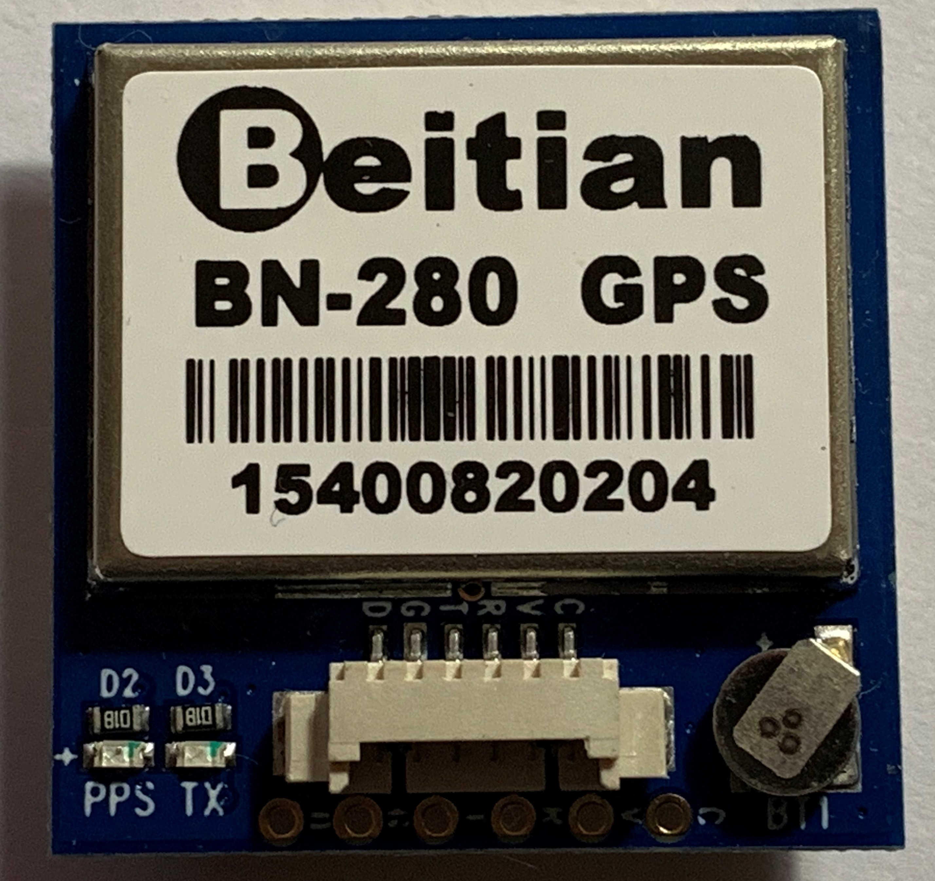
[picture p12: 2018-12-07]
images/bn-280-cover.jpg

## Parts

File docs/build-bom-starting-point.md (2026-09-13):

# Current Build and BOM Starting Point

The PicoTracker repository preserves a working historical 2018-2019 hardware design. This guide provides a supplier-neutral starting point for new builders to select modern equivalents.

For historical reference, please see the existing files in the following directories:
* [`hardware/`](../hardware/)
* [`cad/`](../cad/)
* [`docs/`](../docs/)

**Important:** Compatibility claims below are marked with their current testing status. Do not assume compatibility for parts marked as *candidate* or *not yet tested* without independent verification.

## Required Functional Blocks

### 1. STM8 / HC-12 Radio
* **Required Characteristics:** 433 MHz operation with an STM8S003F3 and a compatible Si4463/Si4438-family radio path. PicoTracker reprograms the STM8S003F3 and controls the radio directly; UART is associated with the original HC-12 module firmware and is not the primary interface used by the maintained PicoTracker firmware.
* **Historical Part:** HC-12 hardware based on STM8S003F3 and Si4463-compatible radio hardware.
* **Current Candidates:**
  * HC-12-compatible STM8S003F3 / Si4463 hardware: *candidate* - [Si4463 Datasheet](https://www.silabs.com/documents/public/data-sheets/Si4464-63-61-60.pdf)
  * Si4438-compatible hardware path: *candidate*

### 2. GPS
* **Required Characteristics:** u-blox M8-compatible GNSS receiver with support for the UBX protocol used by PicoTracker, including UBX-NAV-PVT, and compatible 3.3 V logic.
* **Historical Part:** M8-based modules such as BN-280 and BN-220.
* **Current Candidates:**
  * BN-280 / BN-220 or equivalent u-blox M8-based module: *candidate*
  * Other u-blox M8-compatible GNSS modules supporting UBX-NAV-PVT: *candidate* - [NEO-M8 Hardware Integration Manual](https://content.u-blox.com/sites/default/files/NEO-M8-series-hardware-integration-manual_UBX-13003538.pdf)

### 3. Power Stage
* **Required Characteristics:** AAA lithium primary-cell input with a low-power boost converter providing approximately 3.3 V for the tracker electronics.
* **Historical Part:** AAA lithium primary cell with a boost-converter power stage as represented by the repository's historical hardware design.
* **Current Candidates:**
  * Equivalent low-quiescent-current boost converter suitable for a single AAA lithium primary cell: *candidate*

### 4. Antennas
* **Required Characteristics:** Antenna suitable for the PicoTracker 433 MHz radio path, with impedance and connection method matched to the selected radio hardware and PCB implementation.
* **Historical Part:** Refer to the repository's historical hardware and CAD files for the original RF implementation.
* **Current Candidates:**
  * 433 MHz antenna compatible with the selected radio implementation: *candidate*
  * Alternative 433 MHz antenna configurations: *not yet tested*

### 5. Programming / Debug Interface
* **Required Characteristics:** SWIM (Single Wire Interface Module) support for programming the STM8S003F3.
* **Historical Part:** ST-Link-compatible STM8 programming/debug interface.
* **Current Candidates:**
  * ST-Link V2 or compatible programmer with STM8 SWIM support: *candidate* - [ST-Link V2 User Manual](https://www.st.com/resource/en/user_manual/dm00026748-stlinkv2-in-circuit-debuggerprogrammer-for-stm8-and-stm32-stmicroelectronics.pdf)

### 6. Mechanical Mounting
* **Required Characteristics:** Lightweight mounting that securely houses the PCB and battery while avoiding unnecessary interference with the RF implementation.
* **Historical Part:** Refer to the existing designs in the [`cad/`](../cad/) directory.
* **Current Candidates:**
  * Enclosure or mounting solution based on the existing CAD design: *candidate*
  * Alternative lightweight enclosure materials and designs: *not yet tested*

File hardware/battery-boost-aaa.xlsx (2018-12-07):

Batteryboost AAA BOM
Part | Value | Device | Package | Description | Manufacturer | Manufacturer Part No. | Supplier Part No. | SUPPLIER
BAT1 | Two Clips | BATTERYAAA | BATTERY-AAA | Battery Holders | Keystone | 82 | 302-1139 | RS
C1 | 10uF | C-EUC0805K | C0805K | CAPACITOR, European symbol | Vishay AVX | 08056D106KAT2A | 698-3548 | RS
C2 | 10uF | C-EUC0805K | C0805K | CAPACITOR, European symbol | Vishay AVX | 08056D106KAT2A | 698-3548 | RS
IN | Not Fitted | PINHD-1X2 | 1X02 | PIN HEADER | n/a | n/a | n/a | n/a
L1 | 4.7uH | INDUCTOR1210 | LQH32 | Inductors | Murata | LQH32CN | 469-2782 | RS
OUT | Not Fitted | PINHD-1X2 | 1X02 | PIN HEADER | n/a | n/a | n/a | n/a
R1 | 309k | R-EU_R0603 | R0603 | RESISTOR, European symbol | Vishay | CRCW0603309KFKEA | 679-0188 | RS
R2 | 536k | R-EU_R0603 | R0603 | RESISTOR, European symbol | Panasonic | ERJ3EKF5363V | 814-5448 | RS
U$1 | MCP1640CT | Boost Regulator | SOT23 6 Pin | Synchronous Boost Regulator | Microchip | MCP1640CT-I/CHY | 738-6241 | RS

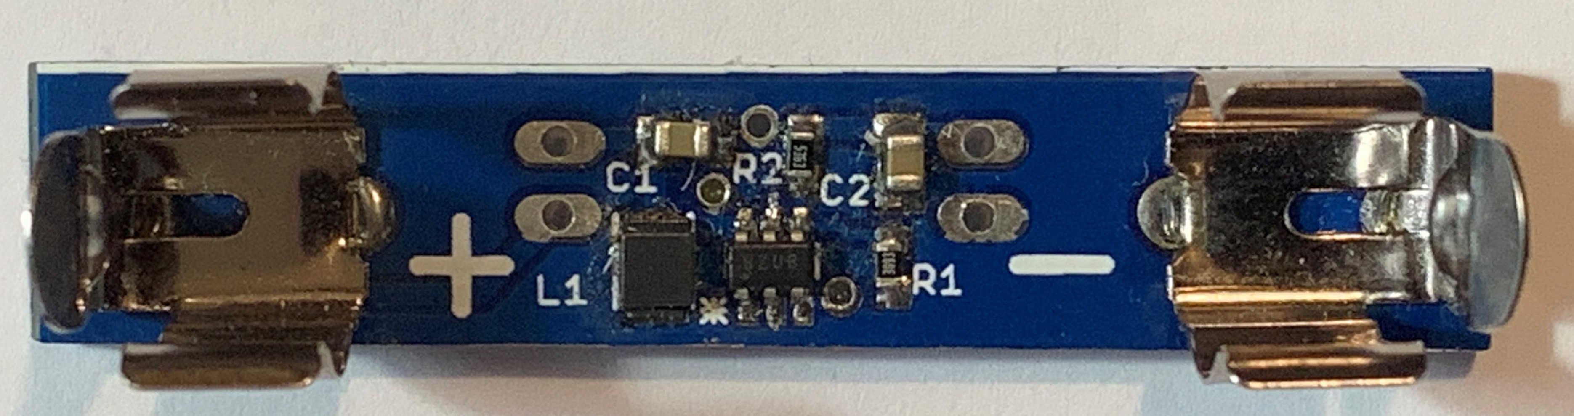
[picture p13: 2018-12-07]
images/battery-booster-component-side.jpg

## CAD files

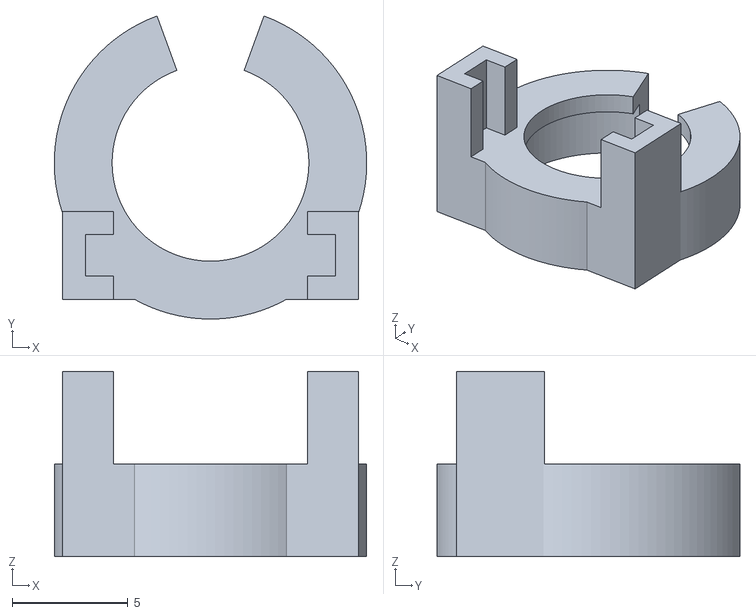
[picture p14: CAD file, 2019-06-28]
cad/battery-clip.stl
13.5 x 13.1 x 8.00

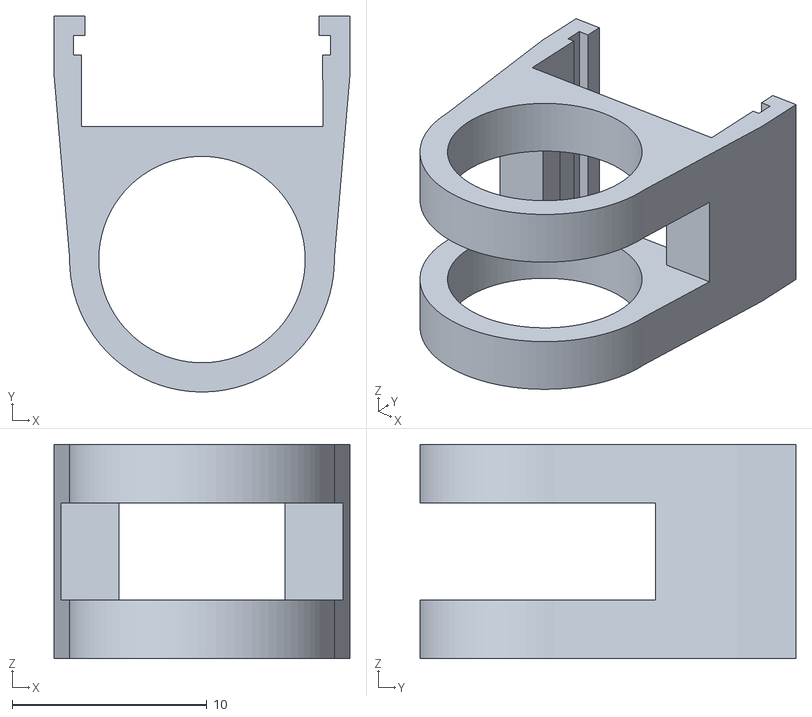
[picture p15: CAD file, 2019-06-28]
cad/hc12-clip.stl
15.2 x 19.3 x 11.0

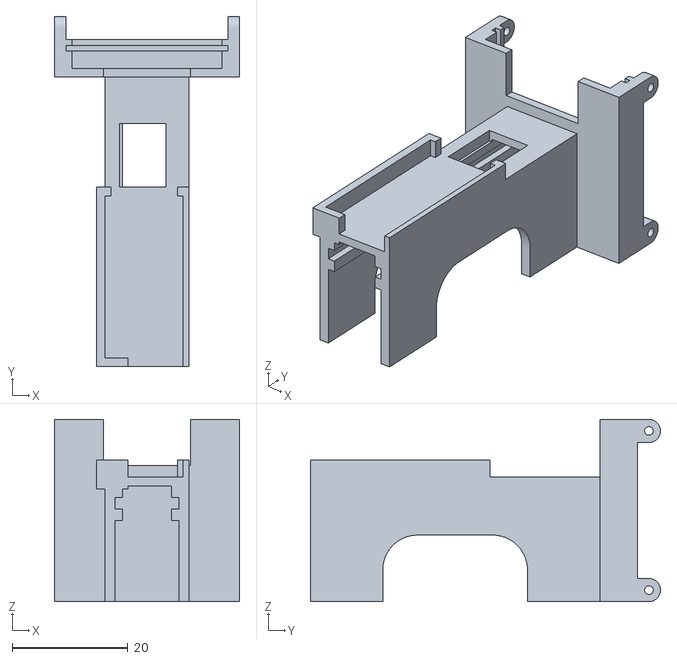
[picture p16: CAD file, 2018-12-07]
cad/tinytrack.stl
32.0 x 60.5 x 31.5

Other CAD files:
cad/tinytrack-v7.f3d

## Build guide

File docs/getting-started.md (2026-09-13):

# Getting started

PicoTracker is small enough to understand end to end, but broad enough to expose real embedded-systems work: power, STM8 firmware, GPS protocols, radio control, telemetry, decoding, testing, CAD, and flight validation.

You do not need tracker hardware to make a useful first contribution.

## First 10 minutes

Prerequisites are Git, Python 3, `make`, and a C compiler such as GCC or Clang.

```sh
git clone https://github.com/ImperialSpaceSociety/PicoTracker.git
cd PicoTracker
make demo
make test
```

`make demo` should report `165 valid frames`. If both commands complete successfully, you have already decoded real PicoTracker telemetry and exercised the firmware's host-testable logic.

To inspect the accepted frames themselves:

```sh
make decode DECODE_ARGS=--print-frames
```

No IAR installation, radio, GPS receiver, or STM8 board is required for this path. You can also run `make simulate` to exercise a complete synthetic tracker flight cycle and fault scenarios before touching hardware. For a guided first code-and-test exercise, continue with [`first-project.md`](first-project.md).

## Reproducible environment

If you do not want to install GCC or SDCC on your host, use the repository Dev Container or run `make container-check` with Docker. Both use the same container definition exercised by CI, including cppcheck and Ruff. See [`development-environment.md`](development-environment.md).

## Why this is a useful project to learn on

PicoTracker is a complete constrained system rather than an isolated library. A contribution can touch embedded C, UART and SPI, u-blox UBX packets, RF control, RTTY, CRCs, low-power operation, telemetry analysis, mechanical design, or verification. The STM8S003F3 provides only 8 KB of flash and 1 KB of RAM, so apparently small design decisions have visible consequences.

The project also contains historical flight hardware and captured telemetry, while the maintained firmware now has host regression tests and an independent STM8 structural build check. That makes it possible to learn from real engineering constraints without needing hardware on day one.

## Choose a path

| If you are interested in... | Start with | A useful first objective |
| --- | --- | --- |
| Embedded firmware | [`firmware/main.c`](../firmware/main.c), [`firmware/gps.c`](../firmware/gps.c) | Understand one acquisition/transmit/sleep cycle and add or improve a regression test |
| GPS and protocols | [`firmware/ubx_parser.h`](../firmware/ubx_parser.h), [`docs/gps.md`](gps.md) | Trace one UBX packet from request through checksum and fix validation |
| RF and telemetry | [`firmware/si_trx.c`](../firmware/si_trx.c), [`firmware/telemetry.c`](../firmware/telemetry.c) | Follow a telemetry byte from frame construction to RTTY channel switching |
| Python/data tooling | [`tools/decode_data.py`](../tools/decode_data.py) | Extend the decoder while keeping it dependency-light and tested |
| Testing and reliability | [`tests/`](../tests/) | Add a boundary, failure-path, or regression case that protects production firmware |
| Simulation and fault injection | [`tools/simulate_tracker.py`](../tools/simulate_tracker.py), [`simulator.md`](simulator.md) | Reproduce GPS loss, measurement faults, or telemetry loss without hardware |
| Hardware and RF | [`docs/hc12.md`](hc12.md), [`hardware/`](../hardware/) | Revalidate a component, interface, measurement, or current replacement part |
| Mechanical design | [`cad/`](../cad/) | Review or improve a lightweight mounting or enclosure part |
| Documentation | [`docs/`](./) | Turn a difficult subsystem into a short reproducible guide |

## Understand the system before changing it

The root [`README.md`](../README.md) contains the architecture and firmware-cycle diagrams. The most useful references after that are:

- [`telemetry-format.md`](telemetry-format.md) for the transmitted frame
- [`status-word.md`](status-word.md) for diagnostic telemetry
- [`development.md`](development.md) for STM8 programming and debugging
- [`tests/README.md`](../tests/README.md) for the regression suite and SDCC structural check
- [`roadmap.md`](roadmap.md) for meaningful extension directions

## Make a first contribution

Look for open issues labelled [`good first issue`](https://github.com/ImperialSpaceSociety/PicoTracker/issues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). Pick one narrow problem, make the smallest complete change, add or update tests where appropriate, and run:

```sh
make quality
make test
```

If your change affects target firmware structure and you have an STM8-capable SDCC installation, also run:

```sh
make stm8
```

A good first pull request does not need to redesign the tracker. A clear test, decoder improvement, documentation correction, or small firmware fix that makes the system easier to understand or trust is valuable.

## When hardware becomes useful

Hardware is needed for RF measurements, power profiling, environmental testing, programming the STM8, and validating physical changes. It is not required for most documentation, decoder, regression-test, protocol, or repository work.

If you want to build a tracker, treat the 2018-2019 hardware files as a validated historical design rather than a current bill of materials. Recheck component availability, RF configuration, power behaviour, and local radio/balloon requirements before flight.

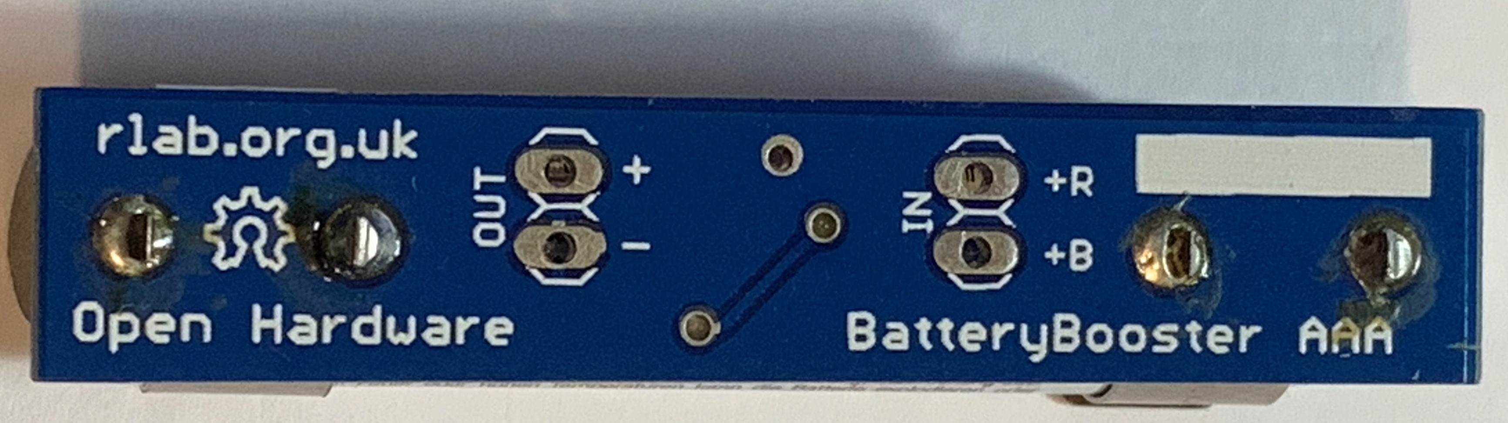
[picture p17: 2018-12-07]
images/battery-booster-solder-side.jpg

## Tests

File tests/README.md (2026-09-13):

# Host tests

These tests exercise hardware-independent firmware and tooling logic on the development machine. Current coverage includes:

- fixed-width numeric formatting
- telemetry latitude, longitude, and temperature formatting
- maximum telemetry-frame capacity and dynamic field layout
- telemetry CRC reference and captured-frame vectors
- GPS operational-status packing
- u-blox checksum and NAV-PVT fix-validity rules
- synthetic UBX byte-stream packets, checksum rejection, payload bounds, and strict ACK/NAK parsing
- radio temperature conversion
- radio synthesizer fixed-point calculations and supported frequency bands
- GPS altitude conversion and clamp behavior
- altitude-dependent sleep policy
- Python telemetry decoder CRC handling and sample-capture decoding
- hardware-independent simulator behaviour, fault recovery, telemetry vectors, and decoder-compatible captures
- release metadata, release-note extraction, and IAR project-reference integrity

From the repository root, run the complete host suite with:

```sh
make test
```

The host tests complement the STM8/IAR build and physical hardware validation; they do not replace target testing.

## STM8 structural target check

When SDCC with STM8 support is installed, run:

```sh
make stm8
```

This compiles and links the production C sources with SDCC's STM8 backend and checks the STM8S003F3 flash/RAM window. A compatibility shim supplies the IAR register names and removes IAR-specific interrupt declarations, so the generated image is **not flashable** and does not replace the required IAR build or hardware validation. It provides an independent STM8 data-model, code-generation, cross-module link, and approximate size check.

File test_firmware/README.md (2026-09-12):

# Test firmware

This directory contains historical HC-12 test projects used during PicoTracker development.

- `HC12CW/` uses continuous transmission to check output frequency, frequency drift, and RF output power.
- `HC12MOD/` exercises RTTY modulation, baud rate, and timer behaviour.

These projects are separate from the main tracker firmware in `firmware/`.
For the active tracker firmware, see [`../firmware/`](../firmware/). Build and programming notes are in [`../docs/development.md`](../docs/development.md).

## Release status

These projects are preserved as historical diagnostic firmware and are **not release-qualified**. They contain older copies of radio and power-management code and are excluded from the PicoTracker `v1.4.0` firmware validation gates. Use `firmware/` for maintained production code.

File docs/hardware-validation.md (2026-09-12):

# Hardware validation matrix

This matrix records the target-validation status used for PicoTracker releases. Host tests and CI complement, but do not replace, target checks.

**v1.4.0 release status (2026-09-13):** approved by the maintainer following target/hardware validation. Detailed IAR version/build-size output, RF measurements, power measurements, environmental measurements, and binary artifacts were not archived with this release. The repository independently records passing host regression tests plus the SDCC STM8 structural compile/link check.

## Build configurations

| Configuration | Intended use | Status |
| --- | --- | --- |
| HC-12 with 32 MHz TCXO | Primary maintained configuration | Maintainer validated |
| HC-12 with original 30 MHz crystal | Compatibility configuration | Maintainer validated |
| QFN radio/select-pin path | Automatic radio detection path | Maintainer validated |
| TSSOP radio/select-pin path | Automatic fallback path | Maintainer validated |

## Required tests

| Test | Acceptance criterion | Status |
| --- | --- | --- |
| IAR Debug build | Clean build, zero errors | Maintainer validated |
| IAR Release build | Clean build, zero errors | Maintainer validated |
| Flash/program | ST-LINK programs and verifies target | Maintainer validated |
| Cold boot | Tracker starts reliably after full power removal | Maintainer validated |
| Radio identification | Supported Si4463/Si4438 device is detected on the correct select pin | Maintainer validated |
| GPS configuration | Required UBX configuration commands are acknowledged | Maintainer validated |
| Valid GPS fix | Valid 3D `gnssFixOK` solution is accepted | Maintainer validated |
| GPS degraded mode | Loss of GPS does not block subsequent telemetry indefinitely | Maintainer validated |
| RTTY transmit | Stable 433 MHz RTTY output at configured baud and frequency | Maintainer validated |
| Pips mode | Startup/pip transmissions complete without deadlock | Maintainer validated |
| Radio failure path | CTS/radio failure exits through bounded error handling | Maintainer validated |
| Telemetry CRC | Captured frame passes decoder CRC validation | Maintainer validated |
| Telemetry fields | Time, position, altitude, status, voltage, and temperature decode plausibly | Maintainer validated |
| Radio measurements | Voltage and temperature readings are plausible across normal range | Maintainer validated |
| Sleep cadence | One AWU interval through 3000 m policy boundary, two above 3000 m | Maintainer validated |
| Clock recovery | MCU returns to HSI after active halt and continues normal operation | Maintainer validated |
| Power consumption | Sleep and active currents are measured and recorded | Maintainer validated |
| Extended run | Repeated acquisition/transmit/sleep cycles complete without lockup | Maintainer validated |
| Low-temperature test | Tracker remains operational at the selected environmental test point | Maintainer validated |

## Validation record

For future releases, record the date, tester, hardware revision, radio package, oscillator, GPS module, battery/power source, IAR version, firmware commit SHA, observed RF frequency, firmware size, and links to captured telemetry or test notes.

For `v1.4.0`, the maintainer supplied the release authorization and reported successful target/hardware operation. The detailed quantitative record above was not retained, so the status is recorded as maintainer-validated rather than reconstructed from unavailable measurements.

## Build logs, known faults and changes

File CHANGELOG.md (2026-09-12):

# Changelog

All notable changes to PicoTracker are documented here.

## 1.4.0 - 2026-09-13

### Added

- Host-side regression tests for numeric formatting, UBX protocol handling, telemetry CRC and field formatting, status packing, radio temperature conversion, sleep policy, and telemetry decoding.
- Bounded GPS acquisition and radio command failure handling.
- Explicit UBX checksum, payload-length, and navigation-fix validation.
- Reorganized project documentation, test infrastructure, and release-preparation material.
- Added a repeatable SDCC STM8 structural compile/link and flash/RAM size check.

### Changed

- Radio initialization now follows a reset and `POWER_UP` sequence before normal commands.
- Oscillator source and frequency configuration are centralized.
- Altitude-dependent sleep behavior is explicit and host-tested.
- Telemetry decoder runs without third-party dependencies for normal decoding.
- Replaced floating-point radio synthesizer arithmetic with exact integer fixed-point calculations and removed unused firmware helpers to reduce flash use.

### Fixed

- High-altitude and longitude numeric formatting overflow.
- Potential UBX payload-buffer overflow, malformed ACK acceptance, and acceptance of corrupted packets.
- Maximum-length telemetry frame buffer sizing and signed 8-bit transmission-length limits.
- Unbounded GPS, UART, clock-switch, and Si4463 peripheral waits in normal operation.
- Optimizer-removable GPS and radio timing delays.
- Radio ADC and RTTY channel-switch failures that could otherwise be reported or transmitted silently.
- Degraded GPS acquisition overwriting the last accepted navigation solution.
- Signed radio-temperature conversion, field saturation, and TCXO power-down handling.

## 1.3 - 2019-03-07

Historical release tagged `v1.3` in the repository.

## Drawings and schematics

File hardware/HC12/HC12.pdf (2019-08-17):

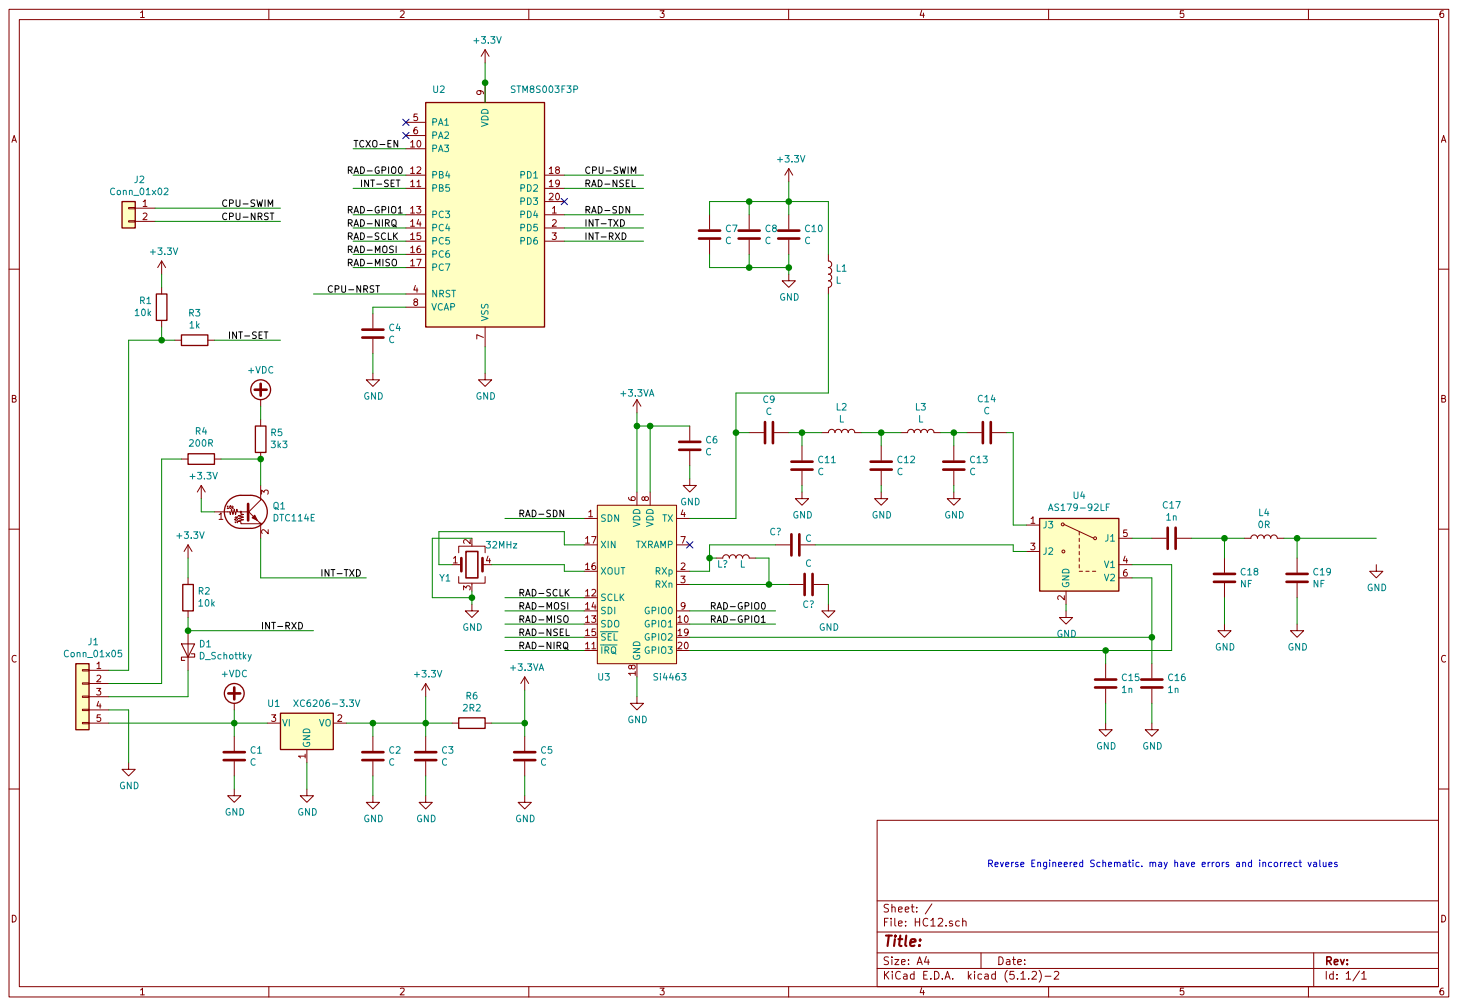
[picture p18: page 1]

9 PA3 10 PD3 20 PB5 11 PB4 12 PC3 13 PC4 14 PC5 15 PC6 16 PC7 17 PD1 18 PD2 19 U2 STM8S003F3P CPU-SWIM
RAD-SCLK RAD-MOSI RAD-MISO GND
INT-SET D1D_Schottky

RAD-NSEL TCXO-EN

RAD-GPIO0 RAD-GPIO1 RAD-NIRQ
INT-SET

CPU-NRST CPU-SWIM
CPU-NRST

RAD-SCLK RAD-MOSI RAD-MISO
+3.3VAC5 C GND

RAD-NSEL RAD-NIRQ

Id: 1/1 Title: File: HC12.sch Sheet: /

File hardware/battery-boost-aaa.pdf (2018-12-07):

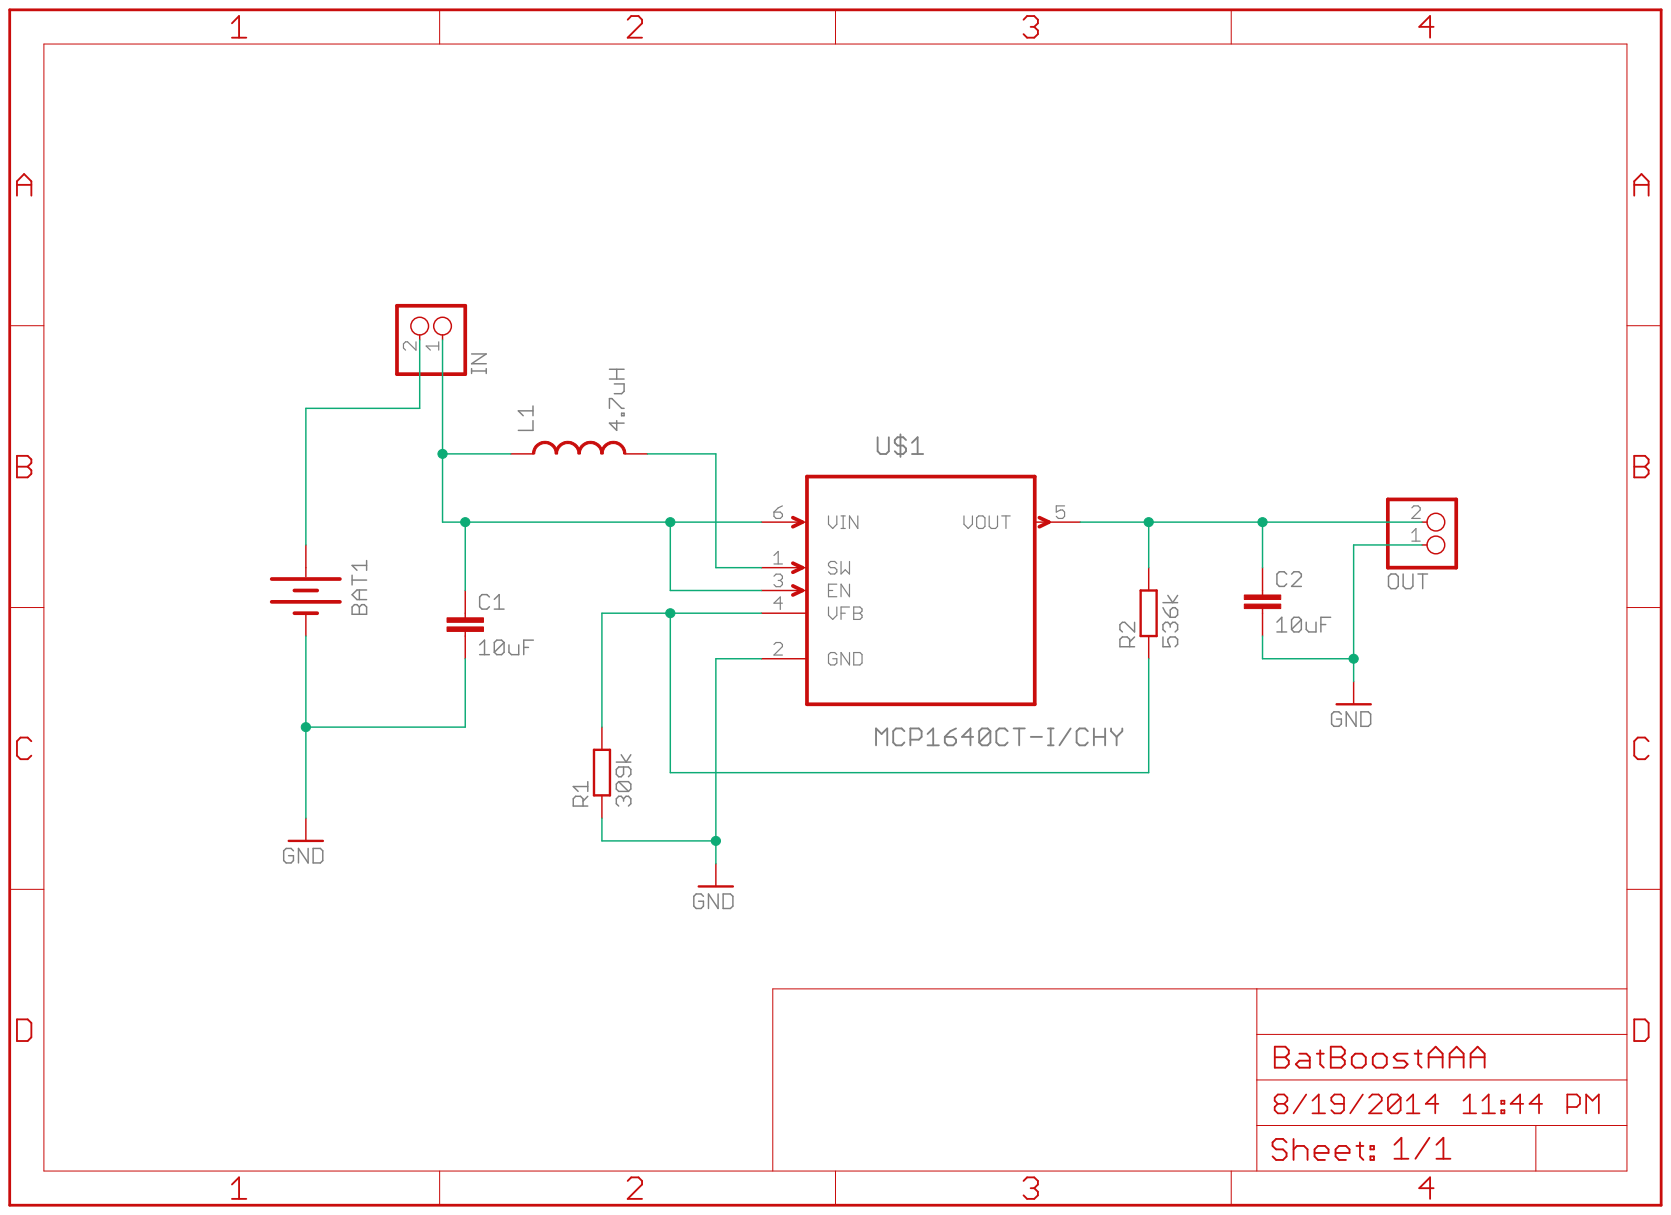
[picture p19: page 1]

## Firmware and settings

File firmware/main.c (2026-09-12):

/*
* main.c  Main Code Module
*
* Pico Balloon Tracker using HC12 radio module and GPS
* HC12 Module with STM8S003F3 processor and silabs Si4463 Radio
*
* This Branch is for build with TCXO Oscillator only
* includes enable of TCXO, 32MHz Clock and config changes to Si4463
*
* Derived Work Copyright (c) 2018 Imperial College Space Society
* From original work Copyright (C) 2014  Richard Meadows <richardeoin>
*
*
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
* THE SOFTWARE IS PROVIDED "AS IS", WITHOUT WARRANTY OF ANY KIND,
* EXPRESS OR IMPLIED, INCLUDING BUT NOT LIMITED TO THE WARRANTIES OF
* MERCHANTABILITY, FITNESS FOR A PARTICULAR PURPOSE AND
* NONINFRINGEMENT. IN NO EVENT SHALL THE AUTHORS OR COPYRIGHT HOLDERS BE
* LIABLE FOR ANY CLAIM, DAMAGES OR OTHER LIABILITY, WHETHER IN AN ACTION
* OF CONTRACT, TORT OR OTHERWISE, ARISING FROM, OUT OF OR IN CONNECTION
* WITH THE SOFTWARE OR THE USE OR OTHER DEALINGS IN THE SOFTWARE.
*/



#include <stdint.h>
#include <iostm8s003f3.h>
#include "HC12Board.h"
#include "si_trx.h"
#include "telemetry.h"

#include "energy.h"
#include "gps.h"
#include "ubx_protocol.h"
#include "sleep_policy.h"
#include "status_word.h"
#include <intrinsics.h>
#include "main.h"


/* A lot of work for the telemetry and GPS communication is taken from
* https://github.com/thasti/utrak
*/

/*

* telemetry format:
* - callsign
* - sentence id
* - time
* - latitude
* - longitude
* - altitude
* - available satellites
* - voltage of the AAA cell(after boosting)
* - op status
* - temperature of radio

*/



/*
* the TX data buffer
* contains ASCII data, which is either transmitted as CW over RTTY
*/
uint16_t tx_buf_length = 0;			/* how many chars to send */
char tx_buf[TX_BUF_MAX_LENGTH] = {SYNC_PREFIX "$$" PAYLOAD_NAME ","};	/* the telemetry buffer initialised with $$ */
extern uint16_t tlm_sent_id_length;
extern uint16_t tlm_alt_length;


/* Retry counters and operational status.
 * Bits 7..4: GPS fix poll attempts, saturated at 15.
 * Bits 3..2: GPS configuration status.
 * Bits 1..0: GPS poll status.
 */
static uint8_t ubx_cfg_fail = 0;
static uint8_t ubx_retry_count;
static uint8_t ubx_poll_fail = OP_STATUS_OK;
static uint8_t gps_fix_attempts = 0;





/* current (latest) GPS fix and measurements */
struct gps_fix current_fix;

static uint8_t get_fix(void) {
    ubx_poll_fail = OP_STATUS_OK;
    gps_fix_attempts = 0;

    while (gps_fix_attempts < GPS_FIX_ATTEMPTS_MAX) {
        gps_fix_attempts++;
        if (gps_get_fix(&current_fix)) return 1;

        ubx_poll_fail = OP_STATUS_TRANSIENT_ERROR;
        if ((gps_fix_attempts % UBX_POLL_RETRIES) == 0U) {
            ubx_poll_fail = OP_STATUS_RETRY_EXHAUSTED;
        }
    }

    ubx_poll_fail = OP_STATUS_DEGRADED;
    return 0;
}

static uint8_t gps_power_mode_with_retries(uint8_t on)
{
    uint8_t retry;

    for (retry = 0; retry < UBX_CFG_RETRIES; retry++) {
        if (gps_power_save(on)) {
            return 1;
        }
        ubx_cfg_fail = OP_STATUS_TRANSIENT_ERROR;
    }

    ubx_cfg_fail = OP_STATUS_RETRY_EXHAUSTED;
    return 0;
}

static void get_measurements(void)
{
    uint16_t measurement_status = 0;

    if (si_trx_get_temperature(&current_fix.temp_radio) != SI_TRX_OK) {
        current_fix.temp_radio = 0;
        measurement_status |= OP_STATUS_MEASUREMENT_ERROR;
    }
    if (si_trx_get_voltage(&current_fix.voltage_radio) != SI_TRX_OK) {
        current_fix.voltage_radio = 0;
        measurement_status |= OP_STATUS_MEASUREMENT_ERROR;
    }

    current_fix.op_status = gps_status_pack(gps_fix_attempts, ubx_cfg_fail, ubx_poll_fail) |
                            measurement_status;
}


int main( void )
{
    /* get the clock working and initialise the auto wakeup service*/
    __disable_interrupt();
    if (!InitialiseSystemClock()) return 1;
    InitialiseAWU(); // auto wake up
    __enable_interrupt();

    /* Start the UART */
    InitialiseUART(); // set up the UART


    /* Initialise Si4060 interface */
    si_trx_init();

    /* indicate that it is alive!*/
    telemetry_start(TELEMETRY_PIPS, 3);


    /* Initialise GPS */
    gps_startup_delay(); // wait 1 sec for GPS to start up




    for(ubx_retry_count=0; ubx_retry_count < UBX_CFG_RETRIES; ubx_retry_count++){ // Configure Power Save Mode
        if((gps_set_power_save())) break;
        ubx_cfg_fail = OP_STATUS_TRANSIENT_ERROR;
        if(ubx_retry_count == (UBX_CFG_RETRIES -1)) ubx_cfg_fail = OP_STATUS_RETRY_EXHAUSTED;
    }

    /* Put the GPS in continuous mode before configuration. */
    (void)gps_power_mode_with_retries(0);

    for(ubx_retry_count=0; ubx_retry_count < UBX_CFG_RETRIES; ubx_retry_count++){ // Setup for no NMEA Messages
        if((gps_disable_nmea_output())) break;
        ubx_cfg_fail = OP_STATUS_TRANSIENT_ERROR;
        if(ubx_retry_count == (UBX_CFG_RETRIES -1)) ubx_cfg_fail = OP_STATUS_RETRY_EXHAUSTED;
    }

    for(ubx_retry_count=0; ubx_retry_count < UBX_CFG_RETRIES; ubx_retry_count++){ // Setup for only GPS mode
        if((gps_set_gps_only())) break;
        ubx_cfg_fail = OP_STATUS_TRANSIENT_ERROR;
        if(ubx_retry_count == (UBX_CFG_RETRIES -1)) ubx_cfg_fail = OP_STATUS_RETRY_EXHAUSTED;
    }

    for(ubx_retry_count=0; ubx_retry_count < UBX_CFG_RETRIES; ubx_retry_count++){ // Setup for High Altitude
        if((gps_set_airborne_model())) break;
        ubx_cfg_fail = OP_STATUS_TRANSIENT_ERROR;
        if(ubx_retry_count == (UBX_CFG_RETRIES -1)) ubx_cfg_fail = OP_STATUS_RETRY_EXHAUSTED;
    }


    /* Get a single GPS fix from a cold start. Does not carry on until it has a
    * solid fix
    */
    get_fix();
    get_measurements();


    /* Activate power save mode after the initial acquisition attempt. */
    (void)gps_power_mode_with_retries(1);


    for(ubx_retry_count=0; ubx_retry_count < UBX_CFG_RETRIES; ubx_retry_count++){ // Save setup to GPS flash
        if((gps_save_settings())) break;
        ubx_cfg_fail = OP_STATUS_TRANSIENT_ERROR;
        if(ubx_retry_count == (UBX_CFG_RETRIES -1)) ubx_cfg_fail = OP_STATUS_RETRY_EXHAUSTED;
    }



    while (1)
    {
	/* Turn the UART back on. 0 enables the UART*/
	uart_power_save(0);

	/* now wake up the GPS */
	gps_wake_up();

	/* Put the GPS in full power mode, but continue if it does not ACK. */
	(void)gps_power_mode_with_retries(0);

	/* get the GPS fix */
        get_fix();

	/* Return the GPS to power-save mode without blocking telemetry forever. */
	(void)gps_power_mode_with_retries(1);


	/* save power by turning off UART on STM8,  1 to turn off UART*/
	uart_power_save(1);

	/* get voltage  and temperature*/
        get_measurements();

	/* create the telemetry string */
	prepare_tx_buffer();

	/* 10 start pips */
	telemetry_start(TELEMETRY_PIPS, 10);

	/* Sleep Wait */
	while (telemetry_active());


	/* send telemetry over RTTY */
	tx_buf_length  = TX_BUF_FRAME_END;
	telemetry_start(TELEMETRY_RTTY, tx_buf_length);

	/* Sleep Wait */
	while (telemetry_active());


	/* Sleep for one AWU interval normally and two intervals above 3000 m. */
	if (!Switch_to_LSI_clock()) return 1;
	{
		uint8_t sleep_intervals;

		InitialiseAWU();
		sleep_intervals = tracker_sleep_intervals_for_altitude(current_fix.alt);
		while (sleep_intervals > 0) {
			__halt();
			sleep_intervals--;
		}

		DeInitAWU();
		if (!Switch_to_HSI_clock()) return 1;
	}

    } /* while(1)*/

} /* main()*/

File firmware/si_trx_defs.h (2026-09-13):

/*
 * Definitions and macros for Si Labs Tranceivers
 *
 * for Pico Balloon Tracker using HC12 radio module and GPS
 * HC12 Module with STM8S003F3 processor and silabs Si4463 Radio
 *
 * Derived Work Copyright (c) 2018 Imperial College Space Society
 * From original work Copyright (C) 2014  Richard Meadows <richardeoin>
 *
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
 * THE SOFTWARE IS PROVIDED "AS IS", WITHOUT WARRANTY OF ANY KIND,
 * EXPRESS OR IMPLIED, INCLUDING BUT NOT LIMITED TO THE WARRANTIES OF
 * MERCHANTABILITY, FITNESS FOR A PARTICULAR PURPOSE AND
 * NONINFRINGEMENT. IN NO EVENT SHALL THE AUTHORS OR COPYRIGHT HOLDERS BE
 * LIABLE FOR ANY CLAIM, DAMAGES OR OTHER LIABILITY, WHETHER IN AN ACTION
 * OF CONTRACT, TORT OR OTHERWISE, ARISING FROM, OUT OF OR IN CONNECTION
 * WITH THE SOFTWARE OR THE USE OR OTHER DEALINGS IN THE SOFTWARE.
 */

#ifndef SI_TRX_DEFS_H
#define SI_TRX_DEFS_H

#include <stdint.h>

#define SI_TRX_CTS_POLL_LIMIT 5000U


/**
 * =============================================================================
 *                         COMMAND DEFINITIONS
 * =============================================================================
 */

/**
 * Si Boot Commands
 */
enum {
  SI_CMD_POWER_UP		= 0x02,
};
/**
 * Si Common Commands
 */
enum {
  SI_CMD_NOP			= 0x00,
  SI_CMD_PART_INFO		= 0x01,
  SI_CMD_FUNC_INFO		= 0x10,
  SI_CMD_SET_PROPERTY		= 0x11,
  SI_CMD_GET_PROPERTY		= 0x12,
  SI_CMD_GPIO_PIN_CFG		= 0x13,
  SI_CMD_FIFO_INFO		= 0x15,
  SI_CMD_GET_INT_STATUS		= 0x20,
  SI_CMD_REQUEST_DEVICE_STATE	= 0x33,
  SI_CMD_CHANGE_STATE		= 0x34,
  SI_CMD_READ_CMD_BUFF		= 0x44,
  SI_CMD_FRR_A_READ		= 0x50,
  SI_CMD_FRR_B_READ		= 0x51,
  SI_CMD_FRR_C_READ		= 0x53,
  SI_CMD_FRR_D_READ		= 0x57,
};
/**
 * Si Tx Commands
 */
enum {
  SI_CMD_START_TX		= 0x31,
  SI_CMD_WRITE_TX_FIFO		= 0x66,
};
/**
 * Si Rx Commands
 */
enum {
  SI_CMD_PACKET_INFO		= 0x16,
  SI_CMD_GET_MODEM_STATUS	= 0x22,
  SI_CMD_START_RX		= 0x32,
  SI_CMD_RX_HOP			= 0x36,
  SI_CMD_READ_RX_FIFO		= 0x77,
};
/**
 * Si Advanced Commands
 */
enum {
  SI_CMD_GET_ADC_READING	= 0x14,
  SI_CMD_PROTOCOL_CFG		= 0x18,
  SI_CMD_GET_PH_STATUS		= 0x21,
  SI_CMD_GET_CHIP_STATUS	= 0x23,
};

/**
 * =============================================================================
 *                         COMMAND ARGUMENTS
 * =============================================================================
 */

/**
 * Si Power Up
 */
enum {
  SI_POWER_UP_FUNCTION		= 0x01,
  SI_POWER_UP_XTAL		= 0x00,
  SI_POWER_UP_TCXO		= 0x01,
};

/**
 * Si GPIO configuration
 */
typedef uint8_t si_gpio_t;
enum {
  SI_GPIO_PIN_CFG_PULL_ENABLE 			= 0x40, /* enable or disable pull-up resistor */
  SI_GPIO_PIN_CFG_GPIO_MODE_DONOTHING		= 0x00, /* pin behaviour is not changed */
  SI_GPIO_PIN_CFG_GPIO_MODE_TRISTATE		= 0x01, /* input and output drivers are disabled */
  SI_GPIO_PIN_CFG_GPIO_MODE_DRIVE0		= 0x02, /* CMOS output "low" */
  SI_GPIO_PIN_CFG_GPIO_MODE_DRIVE1		= 0x03, /* CMOS output "high" */
  SI_GPIO_PIN_CFG_GPIO_MODE_INPUT		= 0x04, /* GPIO is input, for TXDATA etc, function is not configured here */
  SI_GPIO_PIN_CFG_GPIO_MODE_32K_CLK		= 0x05, /* outputs the 32kHz CLK when selected in CLK32_CLK_SEL */
  SI_GPIO_PIN_CFG_GPIO_MODE_BOOT_CLK		= 0x06, /* outputs boot clock when SPI_ACTIVE */
  SI_GPIO_PIN_CFG_GPIO_MODE_DIV_CLK		= 0x07, /* outputs divided xtal clk */
  SI_GPIO_PIN_CFG_GPIO_MODE_CTS			= 0x08, /* output, '1' when device is ready to accept new command */
  SI_GPIO_PIN_CFG_GPIO_MODE_INV_CNT		= 0x09, /* output, inverted CTS */
  SI_GPIO_PIN_CFG_GPIO_MODE_CMD_OVERLAP		= 0x0a, /* output, '1' if a command was issued while not ready */
  SI_GPIO_PIN_CFG_GPIO_MODE_SDO			= 0x0b, /* output, serial data out for SPI */
  SI_GPIO_PIN_CFG_GPIO_MODE_POR			= 0x0c, /* output, '0' while in POR state */
  SI_GPIO_PIN_CFG_GPIO_MODE_CAL_WUT		= 0x0d, /* output, '1' on expiration of wake up timer */
  SI_GPIO_PIN_CFG_GPIO_MODE_WUT			= 0x0e, /* wake up timer output */
  SI_GPIO_PIN_CFG_GPIO_MODE_EN_PA		= 0x0f, /* output, '1' when PA is enabled */
  SI_GPIO_PIN_CFG_GPIO_MODE_TX_DATA_CLK		= 0x10, /* data clock output, for TX direct sync mode */
  SI_GPIO_PIN_CFG_GPIO_MODE_TX_DATA		= 0x11, /* data output from TX FIFO, for debugging purposes */
  SI_GPIO_PIN_CFG_GPIO_MODE_IN_SLEEP		= 0x12, /* output, '0' when in sleep state */
  SI_GPIO_PIN_CFG_GPIO_MODE_TX_STATE		= 0x13, /* output, '1' when in TX state */
  SI_GPIO_PIN_CFG_GPIO_MODE_TX_FIFO_EMPTY	= 0x14, /* output, '1' when FIFO is empty */
  SI_GPIO_PIN_CFG_GPIO_MODE_LOW_BATT		= 0x15, /* output, '1' if low battery is detected */
  SI_GPIO_PIN_CFG_NIRQ_MODE_DONOTHING		= 0x00,
  SI_GPIO_PIN_CFG_SDO_MODE_DONOTHING		= 0x00,
  SI_GPIO_PIN_CFG_DRV_STRENGTH_HIGH		= (0x00 << 5),
  SI_GPIO_PIN_CFG_DRV_STRENGTH_MED_HIGH		= (0x01 << 5),
  SI_GPIO_PIN_CFG_DRV_STRENGTH_MED_LOW		= (0x02 << 5),
  SI_GPIO_PIN_CFG_DRV_STRENGTH_LOW		= (0x03 << 5),
};
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

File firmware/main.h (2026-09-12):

/*
 * main tracker software
 *
 * modified from Stefan Biereigel
 *
 */



#ifndef MAIN_H_
#define MAIN_H_


////////////////////////////////////////////////////////////////////////////////
/* Here is the most important configuration section                           */
////////////////////////////////////////////////////////////////////////////////

/* payload name */
#define PAYLOAD_NAME "ICSPACE14"

/* radio definitions */
#define RADIO_FREQUENCY	434570000
#define RADIO_POWER	0x10
#define RTTY_CHANNEL_SPACING	50         // Corresponds to 760Hz spacing

/* setting up baud rates */

/* 50 baud RTTY */
#define RTTY_BIT_MS		19         // Milliseconds - 1 of bit period
/* 200 baud RTTY */
//#define RTTY_BIT_MS		4         // Milliseconds - 1 of bit period
////////////////////////////////////////////////////////////////////////////////

/* telemetry string prefix for RX synchronisation */
#define SYNC_PREFIX		"  $$"
/* telemetry string postfix for tlm parser */
#define TX_BUF_POSTFIX		"\n\n"

/* number of idle bits to transmit before beginning tlm string tx */
#define NUM_IDLE_BITS	32

/* length of non-GPS-telemetry fields */
#define LAT_LENGTH		9
#define LON_LENGTH		10
#define TIME_LENGTH		6
#define SAT_LENGTH		2
#define ALT_LENGTH_MAX		5
#define VOLT_LENGTH		4
#define OP_STAT_LENGTH		4
#define TEMP_LENGTH		2
#define CHECKSUM_LENGTH		4
/* sentence id is variable length */
#define SENT_ID_LENGTH_MAX	5

#define TX_BUF_POSTFIX_LENGTH	sizeof(TX_BUF_POSTFIX) - 1
/* offset from buffer start to telemetry data */
#define TX_BUF_START_OFFSET 	sizeof(SYNC_PREFIX "$$" PAYLOAD_NAME ",") - 1
#define TX_BUF_SENT_ID_START	TX_BUF_START_OFFSET
#define TX_BUF_TIME_START	TX_BUF_SENT_ID_START + tlm_sent_id_length + 1
#define TX_BUF_LAT_START	TX_BUF_TIME_START + TIME_LENGTH + 1
/* lat and lon fields are one char longer for +/- */
#define TX_BUF_LON_START	TX_BUF_LAT_START + LAT_LENGTH + 1 + 1
#define TX_BUF_ALT_START	TX_BUF_LON_START + LON_LENGTH + 1 + 1
#define TX_BUF_SAT_START	TX_BUF_ALT_START + tlm_alt_length + 1
#define TX_BUF_VOLT_START	TX_BUF_SAT_START + SAT_LENGTH + 1
#define TX_BUF_OP_STAT_START	TX_BUF_VOLT_START + VOLT_LENGTH + 1
/* temperature field is one char longer for +/- */
#define TX_BUF_TEMP_START	TX_BUF_OP_STAT_START + OP_STAT_LENGTH + 1
#define TX_BUF_CHECKSUM_START	TX_BUF_TEMP_START + TEMP_LENGTH + 1 + 1
#define TX_BUF_POSTFIX_START	TX_BUF_CHECKSUM_START + CHECKSUM_LENGTH
#define TX_BUF_FRAME_END	(TX_BUF_POSTFIX_START + TX_BUF_POSTFIX_LENGTH)
/* checksum parameters */
#define TX_BUF_CHECKSUM_BEGIN	sizeof(SYNC_PREFIX "$$") - 1
#define TX_BUF_CHECKSUM_END	TX_BUF_CHECKSUM_START - 1

#define TX_BUF_MAX_LENGTH	(TX_BUF_START_OFFSET + \
				SENT_ID_LENGTH_MAX + 1 + TIME_LENGTH + 1 + \
				LAT_LENGTH + 1 + 1 + LON_LENGTH + 1 + 1 + \
				ALT_LENGTH_MAX + 1 + SAT_LENGTH + 1 + VOLT_LENGTH + 1 + \
				OP_STAT_LENGTH + 1 + TEMP_LENGTH + 1 + 1 + \
				CHECKSUM_LENGTH + TX_BUF_POSTFIX_LENGTH)





#endif

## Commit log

2018-12-07 Added directories and content
    Added docs, images , CAD and hardware
    [BatBoostAAA.xlsx, TinyTrack v7.f3d, TinyTrack.stl]
2018-12-09 Create energy and gps file
    Create energy.c and .h for clik and power management
    Create gps.c and gps.h for GPS and UART functions
2018-12-09 Fixes after test of UART
    [gps.c]
2018-12-15 Tried to revert back
    [gps.c]
2018-12-17 playing around with the uart receive and transmit
2018-12-17 Finally got the Uart receive data working without errors
    [energy.c, gps.c]
2018-12-17 The program now polls the GPS and get back the data in a long string.
    Currently does not parse the string though. There are now significant memory issues.
    [energy.c, gps.c, main.c]
2018-12-18 Got the mcu to communicate with gps.
    I have not tested the gps in the open air so I have not gotten a gps fix yet. I will have to work on that.
    [gps.c, main.c]
2018-12-18 resolved some git errors
    [gps.c]
2018-12-20 cleaned out unwanted code that is not used. Added some functions to test out the power saving features of the stm8 and ublox
2018-12-20 Add support for HC12 with QFN
    The HC12 with a QFN STM8S003 uses a different SPI select pin Add #define for this
2018-12-24 Removed the use of interrupts when receiving uart message from gps
2018-12-24 removed interrupted rx
2019-01-01 Added timeouts to gps communication
    Added time out so GPS configuration and poll fundtions.
    Added an OP_STAT operational status long word to communcate if we had any problems
    Adde code to include the voltage and temperature, but not working yet!
    [gps.c, main.c, main.h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]
2019-01-10 Got the gps to go into power saving mode after it aquires a fix
    Also reduced the timeout for ubx poll to 1 second from 10 seconds@ 16MHZ
    [gps.c, main.c, main.h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]
2019-01-12 Done some powersaving with the gps and stm8 and fixed the telemetry
    Things done:
    -I put the MCU in Active Halt Mode after transmitting each sentence, turning off the Main Voltage regulator and powering down the cpu. This will save power while it waits for around a 30 seconds before transmitting again.
    -Verified that the UBLOX is running on the ON-OFF mode, that wakes up only when polled but keeps track of position in low power mode. This is the best solution I think to save power using software along. The designer of the Utrak tracker also uses the on-off mode and even changed from cyclic mode to On-Off mode. TODO: how to make the GPS consume even less power?
    - Fixed a problem in the telem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
    [energy.c, gps.c, main.c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]
2019-01-12 Fix Battery Voltage and Temperature
    Correct programming error wich stopped the radio voltage and temperature measurements from working
    [main.c, si_trx.c]
2019-01-19 Fixed the power saving problem with GPS and more
    -Switch to low speed clock before going into halt
    -Saves the power save activation to flash so that the GPS stays in power save mode even after it wakes up
    -peripheral clock gating to turn off the clock output to all the unused peripherials
    -reduced the radio power to approximately 10mW
    -Switched back the setting for the TSSOP stm8 package. Can be changed
    [energy.c, gps.c, main.c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]
2019-01-27 Reduce Tx Power level to +10dBm. Add HC12CW Test
    Reduce the transmit power level to +10dBm. Add test utility to test the transmit frequency, frequency drift, and power level by sending CW signal
    [energy.c, main.c, main.h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]
2019-01-27 Add test firmware for modulation timeing tests
    Test firmware to test modulation baud rate and shift with temperature.
2019-02-05 set the sleep time of the MCU to 60s and fixed the bug got fixes with low satallite count
    Also changed the call sign to ICSPACE4, the next flight
    [main.c, main.h]
2019-02-08 Switch to the QFN version
2019-02-26 Removed the requirement for 6 sat fix and reverted back the message to disable all other GPS constellations.
    in the ICSPACE2 & 3 flights, I did not observe incredible fluctuation in the number of satellites. However, with the new UBX-CFG-GNSS message, I saw incredible numbers of satellites used to get a fix, up to 23 satellites. I have a feeling that something went wrong with this command and it was possibly using other constellations besides the American GPS satellites to get those fixes. And when it was not getting 23 sat fixes, it was just not getting any fixes at all!. With GPS satellites, at most we can see 12 satellites.
    [gps.c, main.c, main.h]
2019-03-02 Autodetect the HC12 processor and radio type
    The HC12 comes in different versions with QFN or TSSOP processor and Si4463 or Si4438 Radio, These use different SPI select pins. This replaces #define with auto detect
    [si_trx.c, si_trx_defs.h]
2019-03-27 Add TCXO code
    This raw code for the TCXO version. No selection of TCXO vs XTAL. The changes are to the HC12 board.h to show the hardware change for the TCXO enable and the changed xtal frequency, to sitrx.c to add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
2019-04-11 TX Power level
    Increas TX power level.
    [Battery Clip.stl, HC12 Clip.stl]
2019-07-02 fixed the problem with vcxo variable
    [main.h, si_trx.c]
2019-08-04 Set up for ICSPACE12 and 13. Cleaned up the indentation in main.c.
    Also switched the UBX-CFG-GNSS to not use QZSS. Note that it is set to use GPS satellites only, and channels to use is set to 32.
2019-08-17 Added HC12 schematics
    [HC12.kicad_pcb, HC12.sch]
2019-10-15 did some experiments to see if the debug pips are affecting gps fixes.
    -Removed the sleep section when under 500m so it is easier to debug on the ground
    - removed the pips from telemetry radio during gps search
    - prepared for ICSPACE14 at 434.570Mhz
    [main.c, main.h]
2026-09-12 firmware: track GPS fix attempts in status
    Reimplement the useful diagnostic from the historical ICSPACE5-exclusive-changes branch on current master. Count actual GPS poll attempts, saturate at 15, and document the status bit layout.
    [main.c]
2026-09-12 docs: fix RTTY timing terminology
    [main.h]
2026-09-12 docs: fix synthesiser comments
    [si_trx.c]
2026-09-12 docs: fix GPS power-saving comment
    [gps.c]
2026-09-12 chore: keep telemetry sample trackable
2026-09-12 docs: add current maintainer
2026-09-12 chore: use explicit void prototypes
2026-09-12 docs: clean up GPS driver comments
2026-09-12 docs: clean up radio driver comments
2026-09-12 docs: clean up SPI pin comments
2026-09-12 docs: clean up HC12MOD SPI comments
2026-09-12 docs: clean up HC12CW SPI comments
2026-09-12 docs: fix HC12MOD clock comment
    [energy.c]
2026-09-12 chore: normalize CAD directory name
    [Battery Clip.stl, HC12 Clip.stl, TinyTrack v7.f3d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]
2026-09-12 docs: add CAD directory index
2026-09-12 chore: normalize battery clip filename
    [battery-clip.stl]
2026-09-12 chore: normalize HC12 clip filename
    [hc12-clip.stl]
2026-09-12 chore: normalize tracker mesh filename
    [tinytrack.stl]
2026-09-12 chore: normalize tracker design filename
    [tinytrack-v7.f3d]
2026-09-12 chore: normalize battery boost PDF filename
2026-09-12 chore: normalize battery boost spreadsheet filename
    [battery-boost-aaa.xlsx]
2026-09-12 chore: mark CAD files as binary
2026-09-12 fix: bound UBX payload writes
    [gps.c]
2026-09-12 refactor: track UBX payload checksum
2026-09-12 fix: validate UBX payload checksums
    [gps.c]
2026-09-12 fix: validate UBX ACK checksums
    [gps.c]
2026-09-12 fix: validate NAV-PVT payload before parsing
    [gps.c]
2026-09-12 fix: require valid 3D NAV-PVT fixes
    [main.c]
2026-09-12 fix: bound GPS fix acquisition attempts
    [main.c]
2026-09-12 fix: report GPS acquisition exhaustion
    [main.c]
2026-09-12 fix: mark degraded GPS acquisition state
    [main.c]
2026-09-12 refactor: add bounded GPS power mode helper
2026-09-12 fix: bound runtime GPS wake retries
    [main.c]
2026-09-12 fix: bound runtime GPS sleep retries
    [main.c]
2026-09-12 fix: bound Si4463 CTS polling
    [si_trx.c]
2026-09-12 refactor: propagate Si4463 power-up status
2026-09-12 fix: handle Si4463 part-info transfer failure
    [si_trx.c]
2026-09-12 fix: power up radio before reset commands
    [si_trx.c]
2026-09-12 fix: return invalid radio divider errors
    [si_trx.c]
2026-09-12 fix: propagate Si4463 reset failures
    [si_trx.c]
2026-09-12 fix: report Si4463 transmit startup failures
    [si_trx.c]
2026-09-12 fix: abort RTTY when radio startup fails
    [telemetry.c]
2026-09-12 fix: abort pips when radio startup fails
    [telemetry.c]
2026-09-12 fix: power up radio before QFN part probe
    [si_trx.c]
2026-09-12 fix: power up radio before TSSOP part probe
    [si_trx.c]
2026-09-12 refactor: use configured oscillator frequency
    [si_trx.c]
2026-09-12 refactor: use configured oscillator source
    [si_trx.c]
2026-09-12 refactor: centralize oscillator power control
    [si_trx.c]
2026-09-12 refactor: reuse radio boot for ADC reads
2026-09-12 test: cover signed radio temperature conversion
2026-09-12 fix: use signed radio temperature conversion
    [si_trx.c]
2026-09-12 fix: restore altitude-dependent sleep cadence
    [main.c]
2026-09-12 fix: prepare HSI clock recovery after halt
    [energy.c]
2026-09-12 fix: restore HSI clock after sleep
    [main.c]
2026-09-12 build: pin decoder plotting dependency
2026-09-12 fix: size telemetry buffer for maximum frame
    [main.h]
2026-09-12 test: cover maximum telemetry frame size
2026-09-12 fix: validate UBX ACK frames consistently
    [gps.c]
2026-09-12 test: reject malformed UBX ACK frames
2026-09-12 fix: bound GPS UART transmit waits
    [gps.c]
2026-09-12 fix: bound STM8 clock readiness waits
    [energy.c, main.c]
2026-09-12 fix: report radio measurement failures
    [main.c, si_trx.c]
2026-09-12 fix: propagate RTTY channel switch failures
    [si_trx.c, telemetry.c]
2026-09-12 fix: expose public radio status codes
    [si_trx_defs.h]
2026-09-12 fix: saturate telemetry temperature field
2026-09-12 fix: preserve radio timing delays under optimization
    [si_trx.c]
2026-09-12 fix: initialize all supported radio frequency bands
    [si_trx.c]
2026-09-12 fix: bound UBX response scan length
    [gps.c]
2026-09-12 fix: preserve GPS startup delay under optimization
    [gps.c]
2026-09-12 fix: fail on low-speed clock switch errors
    [main.c]
2026-09-12 fix: preserve last valid GPS fix in degraded mode
    [main.c]
2026-09-12 refactor: reduce STM8 firmware footprint
2026-09-12 refactor: store fixed UBX commands as constants
    [gps.c]
2026-09-13 docs: add current build and BOM starting point guide (#7)
    * docs: add current build and BOM starting point guide
    * docs: address BOM review feedback
2026-09-21 feat(tools): add human-readable decoding for telemetry op_status (#14) (#16)
    * feat(tools): add human-readable decoding for telemetry op_status (#14)
    - Implement decode_op_status, format_op_status, and summarize_op_status in tools/decode_data.py
    - Decode 16-bit packed op_status layout into GPS fix attempts, config status, polling status, degraded mode, and radio ADC measurement failure
    - Add --decode-status CLI argument to tools/decode_data.py to report decoded status in telemetry summaries and alongside --print-frames
    - Preserve raw op_status value and normal decoder behavior without external dependencies
    - Document --decode-status in tools/README.md
    - Add comprehensive regression tests in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
2026-09-23 feat: export accepted telemetry frames as JSON (#23)

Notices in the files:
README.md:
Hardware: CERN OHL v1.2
